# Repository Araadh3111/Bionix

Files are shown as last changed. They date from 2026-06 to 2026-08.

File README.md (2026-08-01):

# Bionix 
## video of the servo opening and closing 
https://www.youtube.com/watch?v=JQe1FLX11hM

An open-source, EMG-controlled bionic hand engineered for the IRIS National Science Fair. Bionix features a custom tendon-driven mechanical design, frictionless brass-rod joints, and an antagonistic elastic return system.

## Overview
Bionix translates raw electromyography (EMG) signals from the user's forearm into precise, articulated finger movements. The system uses a Raspberry Pi Pico to process analog muscle signals and distribute PWM control to a 5-servo array housed inside a custom 3D-printed palm cavity. 

## Features
* **Tendon-Driven Kinematics:** Uses high-tensile braided lines for active flexion and a shock-cord elastic system for passive extension, eliminating the "bowstring" effect.
* **Low-Friction Joints:** Completely screwless 3D-printed phalanges rotating on smooth 2.2mm solid brass dowel pins.
* **Myoelectric Control:** Integrated MyoWare 2.0 sensor for direct muscle-to-machine actuation.
* **Modular Power:** Safely steps down a 7.4V 2S Li-ion battery to 5V (via a 3A+ buck converter) to handle maximum servo stall torque without browning out the logic board.

## System Architecture & Diagrams

### Build progress (signals + enveloping signals)
fds

### Circuit Design and WIRING diagram


### Assembled Design 


### printed hand

### Electronics + hand



# How do I plan on reading Neural signals from the brain
its pretty simple actually, my brain wants to close my hand --> it fires a nerve signal to forearm muscle, which in turn produces a tiny electrical voltage on our skin, electrode pads on our forearm pick up that voltage, the voltage is now pretty weak for the raspberry to read it so the myoware board amplifies it and smooths it into a clean signal. the signal then goes into picos adc pin. then the pico maps out the no to servo position in turn fingers curl

## File Structure

Bionix/

├── CAD/                  # Fusion 360 models, assemblies, and STL files for 3D printing

├── circuit design/       # KiCad schematics (Peak.kicad_sch) for power and signal routing

├── Code/                 # Control software for the Raspberry Pi Pico

├── BOM.csv              # Complete Bill of Materials and cost breakdown

└── README.md             # Project documentation (You are here)

## Hardware Requirements
* Raspberry Pi Pico (RP2040/RP2350)
* 5x Servos (MG90s)
* 1x MyoWare 2.0 Muscle Sensor & Disposable Electrodes
* 1x 5V Buck Converter (>= 3A Output) & 2S Li-ion Battery
* 3D Printed Parts (PLA/PETG recommended)
* *For a full parts list, cost breakdown, and assembly hardware, please refer to the `BOM.csv` file.*

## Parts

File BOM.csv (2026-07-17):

Item | Qty | Unit Cost (USD) | Total (USD) | Source | Notes
MG90S metal-gear servo (test pair) | 2 | 2.98 | 5.96 | https://zbotic.in/product/mg90s-9g-servo-metal-gear-180-degrees-superior-quality/ | Rs.256 verified. 180-deg positional. Pull-test before buying reserve.
MG90S metal-gear servo (reserve) | 3 | 2.98 | 8.945 | https://zbotic.in/product/mg90s-9g-servo-metal-gear-180-degrees-superior-quality/ | Ordered after pull-test passes.
Robocraze EMG muscle sensor kit | 1 | 23.60 | 23.60 | https://www.amazon.in/Robocraze-Muscle-Signal-Sensor-Professional/dp/B073B8P5J9 | Rs.2029. Grip intent signal. Already on hand.
ECG/EMG electrode pads (100 pack) | 1 | 6.78 | 6.78 | https://www.amazon.in/TenTabs-Disposable-Electrodes-Adhesive-Monitoring/dp/B0FRG1DRJ1 | Rs.583. Consumable - fresh pads every EMG session.
Raspberry Pi Pico 2 | 1 | 5.80 | 5.80 | https://robu.in/product/raspberry-pi-pico-2/ | ~Rs.500 - confirm at checkout. New purchase; existing Pico H committed to Vega. RP2350 headroom for EMG processing.
UBEC 5V/7A regulator | 1 | 5.69 | 5.69 | https://www.indianhobbycenter.com/products/ubec-5v-7a | Rs.489. Servo power rail. Already on hand.
Brass rod 2mm dia (10pc) | 1 | 6.97 | 6.97 | https://www.amazon.in/Priyanshu-Decor-10Pcs-Welding-Brazing/dp/B0BZQQDHLJ | Rs.599. CAD joint holes being updated 2.4mm -> 2.05mm to match.
Braided fishing line 40lb 4-strand | 1 | 4.10 | 4.10 | https://www.amazon.in/Pro-Hunter-Fishing-Strands-Accessory/dp/B0CPVNPMRZ?mcid=712e7af3f7ac3c0ebace684aafd9efc9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 | ~Rs.350. Search 'braided fishing line 40lb' on Amazon.in - Ashconfish / Hercules / LinHiver 100m spool all fit. Flexor tendons.
Elastic cord 1.5mm | 1 | 8.13 | 8.13 | https://www.amazon.in/OMX-Elastic-Stretch-Boutique-Bracelet/dp/B09HPSD8BX | Rs.699 / 96m. Extensor return.
PTFE bowden tube 2mm ID x 4mm OD | 1 | 1.73 | 1.73 | https://novo3d.in/blue-ptfe/ | Rs.149 / 1m. Low-friction liner for palm-to-dorsal tendon turn.
TOTAL |  |  | 77.70 |  | ~Rs.6,680. Filament self-funded and excluded. ~Rs.2,520 already on hand (EMG kit + UBEC).

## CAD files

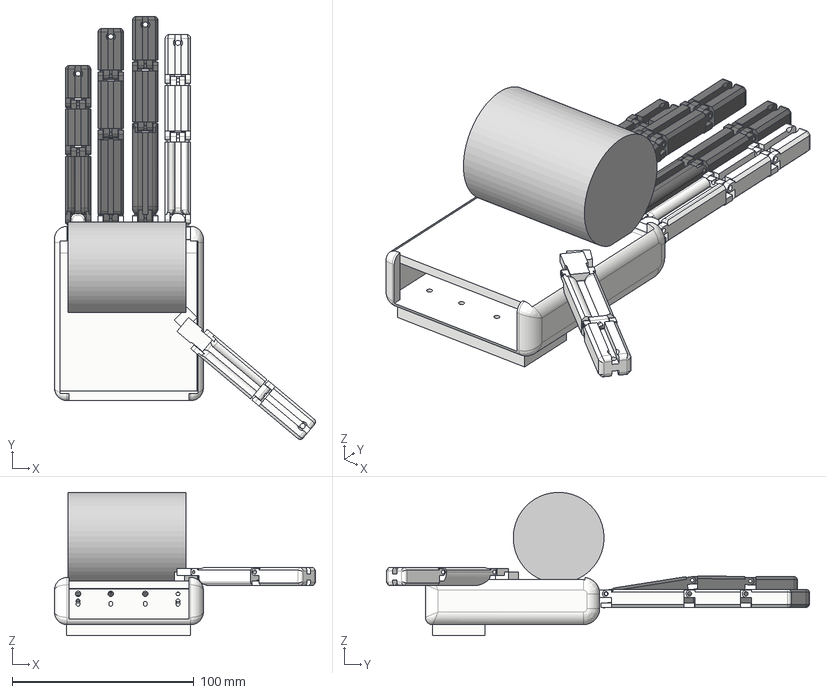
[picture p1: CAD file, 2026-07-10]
CAD/completehand.step
143.8 x 232.9 x 78.8 mm

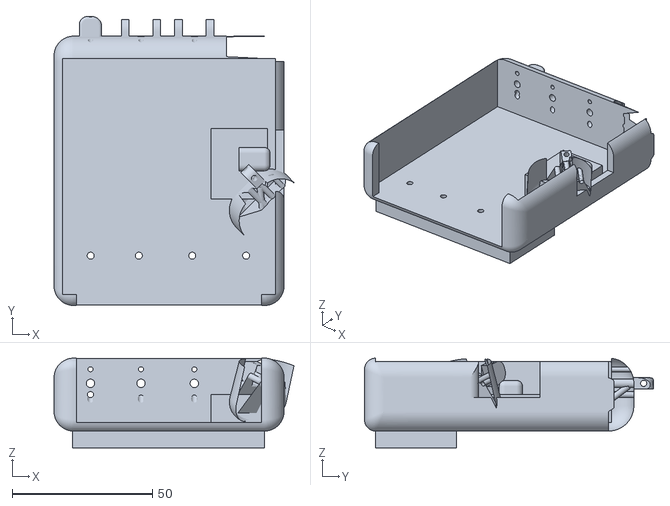
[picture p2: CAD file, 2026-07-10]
CAD/Palm/palm_complete.stl
85.5 x 103.0 x 32.0

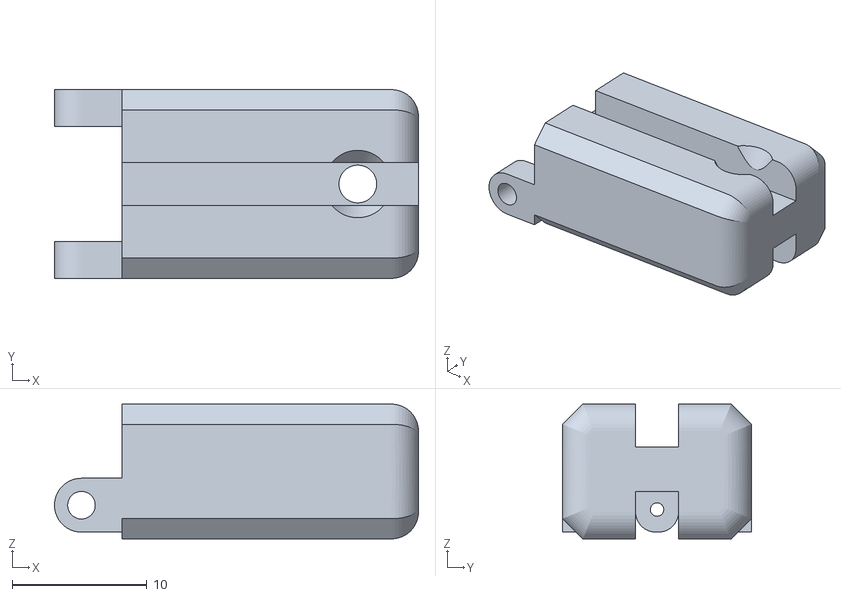
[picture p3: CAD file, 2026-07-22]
CAD/index finger/index_distal.stl
27.0 x 14.0 x 10.0

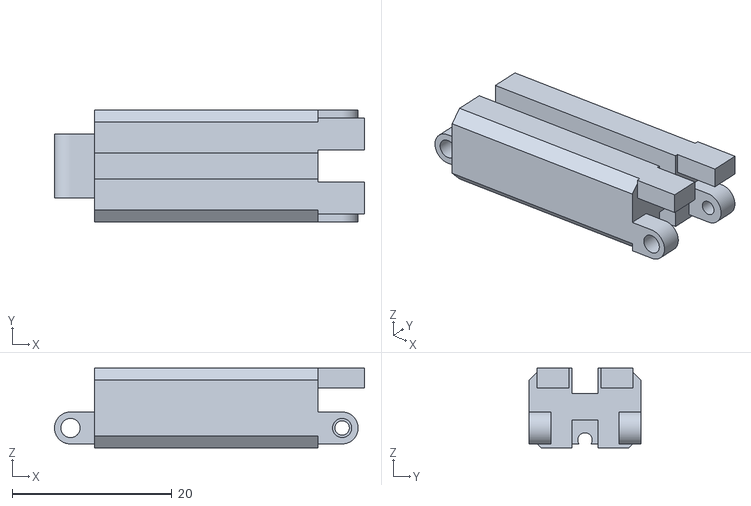
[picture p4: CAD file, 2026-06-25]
CAD/middle finger/middle_middle.stl
38.8 x 14.0 x 10.0

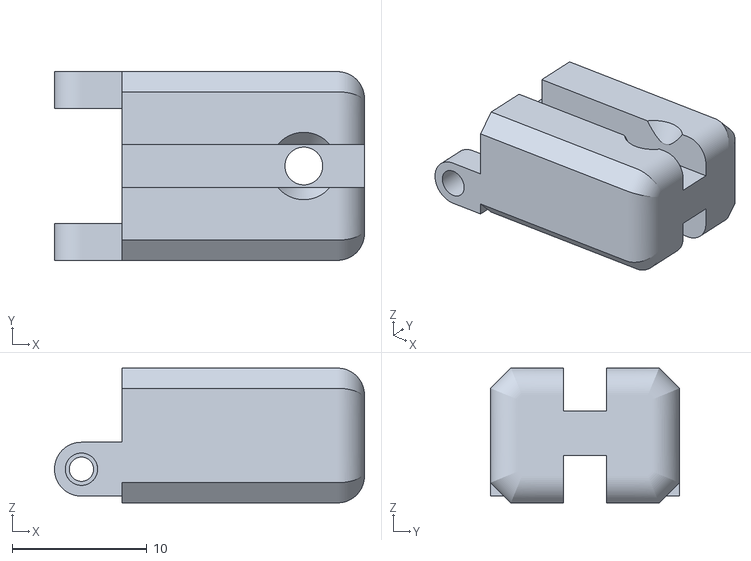
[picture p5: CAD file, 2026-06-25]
CAD/pinky finger/pinky_distal.stl
23.0 x 14.0 x 10.0

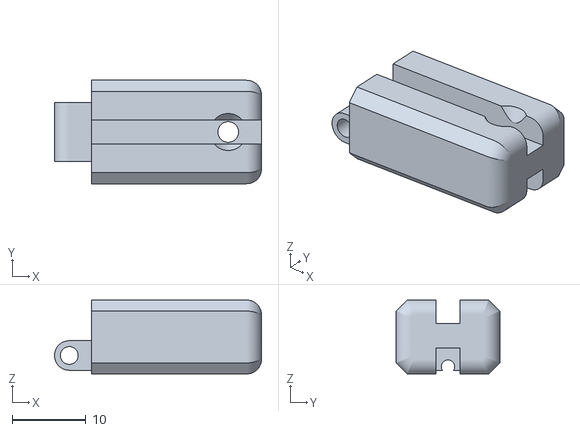
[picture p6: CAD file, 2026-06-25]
CAD/ring finger/ring_distal.stl
28.0 x 14.0 x 10.0

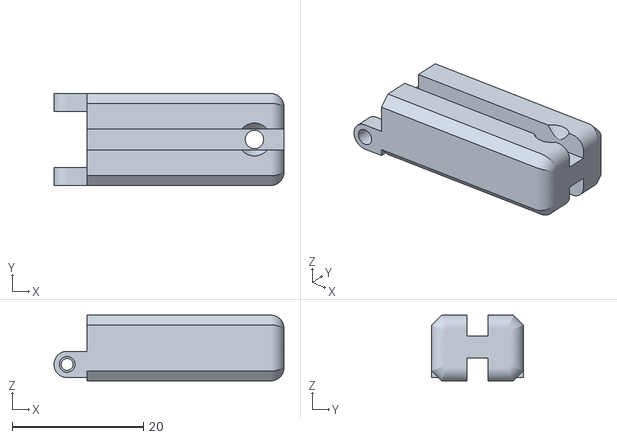
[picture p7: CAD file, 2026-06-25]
CAD/thumb/thumb_distal.stl
35.0 x 14.0 x 10.0

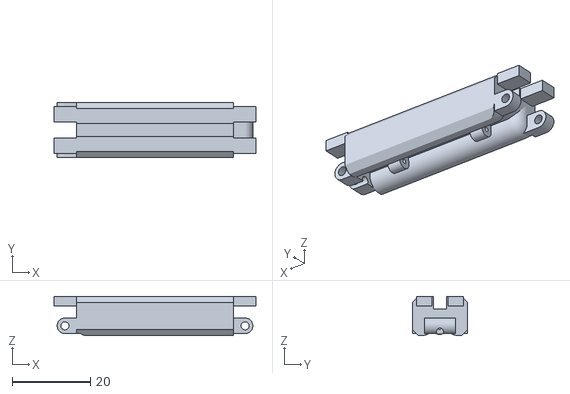
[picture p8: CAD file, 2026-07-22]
CAD/index finger/index_proximal.stl
51.6 x 14.0 x 10.0

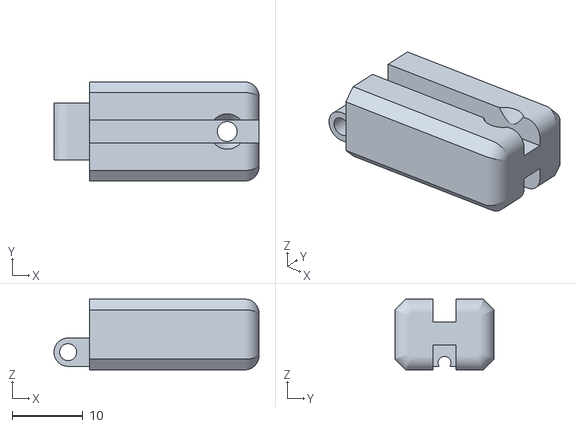
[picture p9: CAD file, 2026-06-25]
CAD/middle finger/middle_distal.stl
29.0 x 14.0 x 10.0

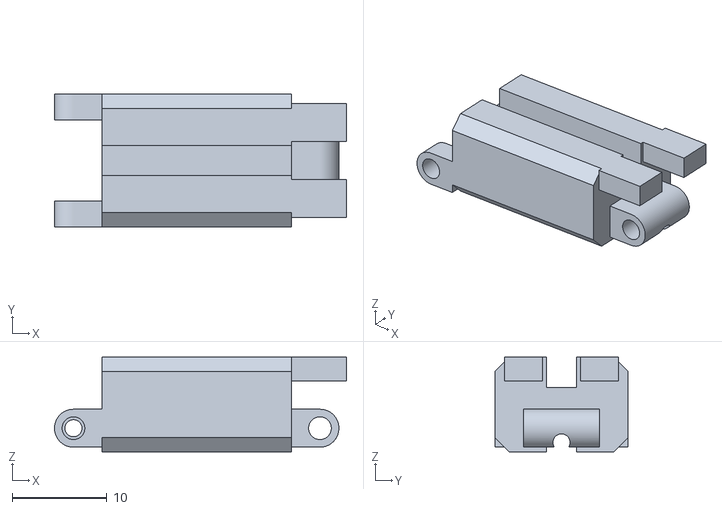
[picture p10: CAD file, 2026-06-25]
CAD/pinky finger/pinky_middle.stl
30.8 x 14.0 x 10.0

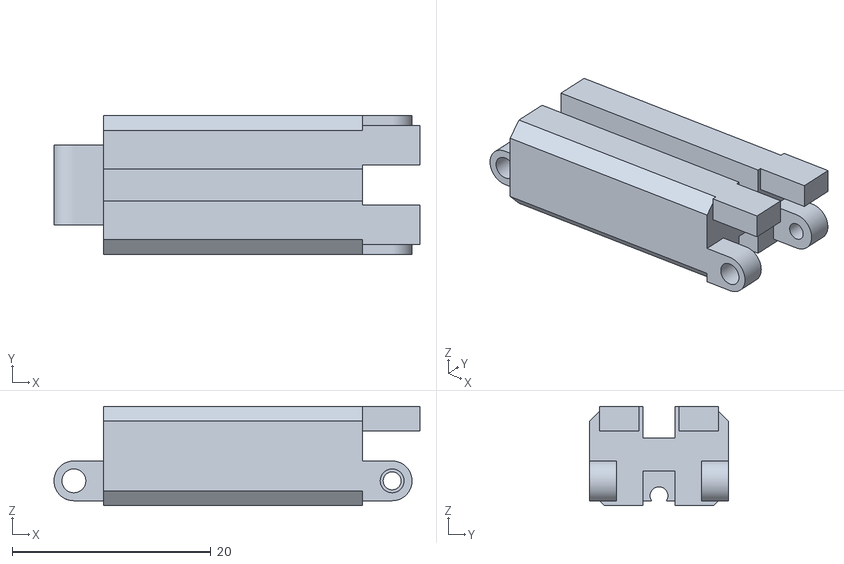
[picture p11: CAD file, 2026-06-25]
CAD/ring finger/ring_middle.stl
36.8 x 14.0 x 10.0

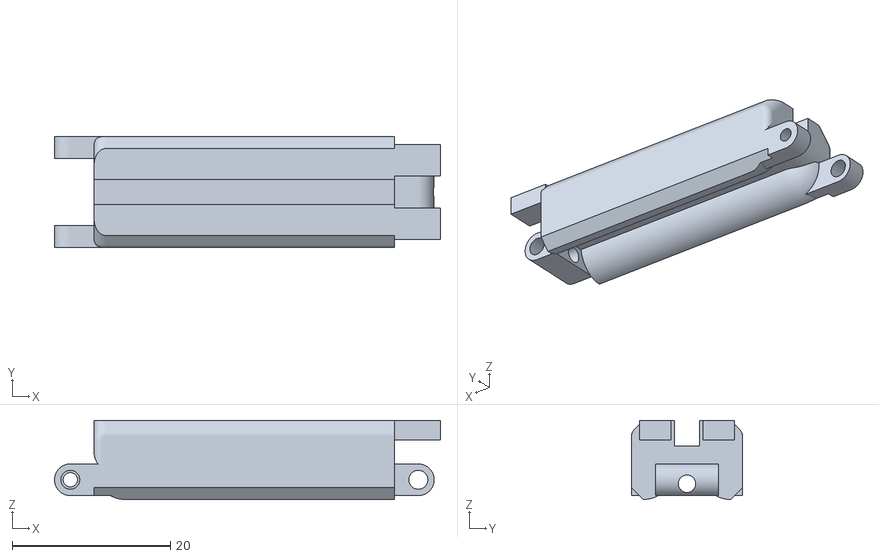
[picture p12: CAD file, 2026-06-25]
CAD/thumb/thumb_proximal.stl
48.8 x 14.0 x 10.0

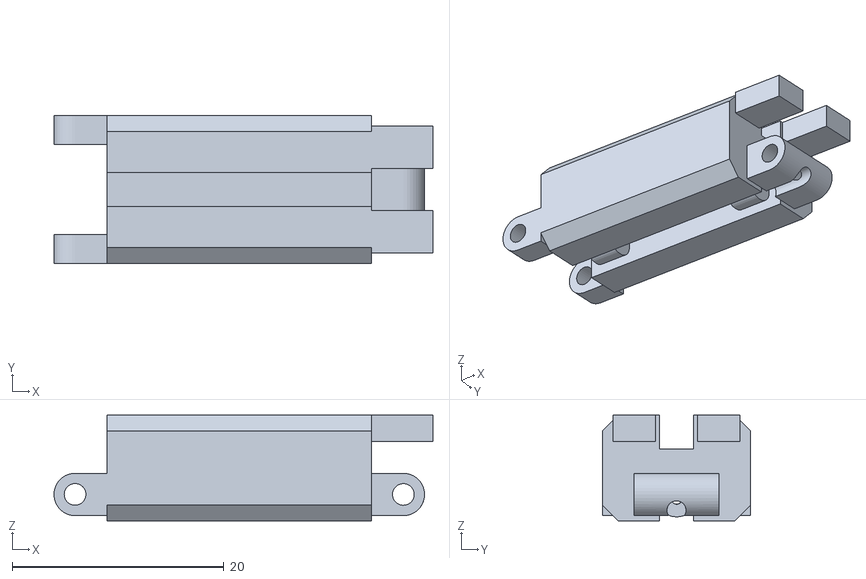
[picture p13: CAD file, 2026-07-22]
CAD/index finger/index_middle.stl
35.8 x 14.0 x 10.0

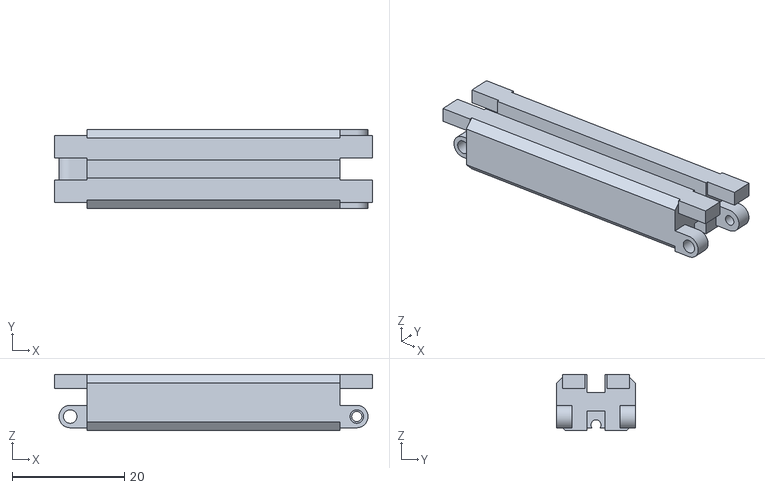
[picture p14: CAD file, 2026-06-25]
CAD/middle finger/middle_proximal.stl
56.6 x 14.0 x 10.0

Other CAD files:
CAD/pinky finger/pinky_proximal.stl
CAD/ring finger/ring_proximal.stl
CAD/completehand.stl

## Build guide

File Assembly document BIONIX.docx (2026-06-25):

# Assembly document BIONIX:-

## Parts list→ servos, RP2040, EMG sensor, wires, threads, elastics, brass rods etc ( to know more about hardware parts refer to BOM.csv)

## Finger Assembly →

A finger contains three parts, the proximal phalanx or the segment that connects to the palm, the middle segment and the distal segment. To connect these all I will be using brass rods of 2mm and insert them in the holes I have made to connect each segment to other also known as the fork and tongue method of connecting or simulating joints

## Thread routing→

A fishing line thread knotted at the very top of the distal phalange runs through the three segments to the palm to create tension, to ensure the threads don’t slip out of the groove channel I have printed small u shaped things to keep it in place from the palm the thread goes to actuator which moves it

## Elastic Routing→

An elastic band running from the top of distal segment to the rectangle box in the bottom portion of the palm to make the finger curl back after pulling

### How does the thumb differ from other fingers?

- Other fingers connect to the palm by a fork or a tongue placed at the top of the palm, the thumb is placed in a unique way by cutting a rectangle shaped cut in the palm and making a thumb mount.

# The electronics:

I am using a raspberry pi("RP2040 / Pico" ) , 5 servos, battery, buck converter and a myoware sensor as my main circuit components. The 5 servos constitute an actuation mechanism where the fishing lines end up getting pulled thus moving the finger the emg sensor picks up signals from the muscle to being contraction or relaxation of the fingers

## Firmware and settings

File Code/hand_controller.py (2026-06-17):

# =====================================================================
#  Unbound Bionics - hand controller  (Raspberry Pi Pico / MicroPython)
#  Pin map taken directly from Peak.net schematic:
#     Thumb  servo -> GPIO10   Index servo -> GPIO11
#     Middle servo -> GPIO12   Ring  servo -> GPIO13
#     Pinky  servo -> GPIO14
#     EMG signal   -> GPIO26 (ADC0)
#  Servos powered from 5V (buck), signal lines from the Pico GPIO.
# =====================================================================

from machine import Pin, PWM, ADC
import time

# ---------- servo driver ----------
SERVO_FREQ = 50          # 50 Hz standard hobby servo
MIN_US = 500             # pulse width at 0 deg   (tune per servo)
MAX_US = 2500            # pulse width at 180 deg (tune per servo)

class Servo:
    def __init__(self, gpio, open_deg=0, closed_deg=110):
        self.pwm = PWM(Pin(gpio))
        self.pwm.freq(SERVO_FREQ)
        self.open_deg = open_deg        # finger straight / open
        self.closed_deg = closed_deg    # finger curled / closed
        self.write(open_deg)

    def write(self, deg):
        deg = max(0, min(180, deg))
        us = MIN_US + (MAX_US - MIN_US) * deg / 180
        # duty_u16: fraction of the 20 ms (20000 us) period
        duty = int(us / 20000 * 65535)
        self.pwm.duty_u16(duty)
        self._deg = deg

    def open(self):   self.write(self.open_deg)
    def close(self):  self.write(self.closed_deg)
    def to(self, frac):  # frac 0.0 (open) .. 1.0 (closed)
        self.write(self.open_deg + (self.closed_deg - self.open_deg) * frac)

# ---------- map fingers to the schematic pins ----------
thumb  = Servo(10)
index  = Servo(11)
middle = Servo(12)
ring   = Servo(13)
pinky  = Servo(14)
FINGERS = [thumb, index, middle, ring, pinky]

# ---------- EMG input ----------
emg = ADC(Pin(26))       # ADC0
def read_emg():
    # average a few samples to smooth noise
    s = 0
    for _ in range(16):
        s += emg.read_u16()
    return s // 16

# ---------- grip presets ----------
def grip_open():
    for f in FINGERS: f.open()

def grip_fist():
    for f in FINGERS: f.close()

def grip_pinch():
    # thumb + index close, rest open  (pinch / hold a pen)
    thumb.close(); index.close()
    middle.open(); ring.open(); pinky.open()

def grip_point():
    # index out, rest closed
    index.open()
    thumb.close(); middle.close(); ring.close(); pinky.close()

def grip_write():
    # writing tripod: thumb + index + middle lightly closed
    thumb.to(0.7); index.to(0.7); middle.to(0.6)
    ring.close(); pinky.close()

# ---------- smooth move (so it doesn't snap) ----------
def smooth_to(frac, steps=20, dly=0.02):
    start = [f._deg for f in FINGERS]
    target = [f.open_deg + (f.closed_deg - f.open_deg) * frac for f in FINGERS]
    for s in range(steps + 1):
        for i, f in enumerate(FINGERS):
            f.write(start[i] + (target[i] - start[i]) * s / steps)
        time.sleep(dly)

# =====================================================================
#  MODE 1 - EMG control
#  Flex muscle -> hand closes. Relax -> opens.
# =====================================================================
EMG_BASELINE = 8000      # calibrate: resting EMG value
EMG_THRESHOLD = 18000    # calibrate: flex above this = close

def calibrate_emg():
    print("Relax your arm... measuring baseline")
    time.sleep(2)
    vals = [read_emg() for _ in range(50)]
    base = sum(vals) // len(vals)
    print("baseline =", base)
    return base

def run_emg_mode():
    base = calibrate_emg()
    thresh = base + 10000
    print("EMG mode running. Flex to close.")
    while True:
        v = read_emg()
        # map EMG strength to grip fraction
        if v > thresh:
            frac = min(1.0, (v - base) / (thresh - base) - 0.0)
            for f in FINGERS: f.to(min(1.0, frac))
        else:
            grip_open()
        time.sleep(0.05)

# =====================================================================
#  MODE 2 - preset cycle (good for the 90-second demo / no EMG)
#  Cycles open -> fist -> pinch -> write so you can film it.
# =====================================================================
def run_demo_cycle():
    seq = [("open", grip_open), ("fist", grip_fist),
           ("pinch", grip_pinch), ("write", grip_write)]
    while True:
        for name, fn in seq:
            print("grip:", name)
            fn()
            time.sleep(2)

# =====================================================================
#  pick a mode here
# =====================================================================
if __name__ == "__main__":
    grip_open()
    time.sleep(1)
    # run_emg_mode()      # <- uncomment for EMG control
    run_demo_cycle()      # <- preset demo cycle (default)

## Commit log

2026-06-17 initial designs have to fix thumb problem
    [BOM.csv, index_distal.step, index_middle.step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]
2026-06-18 Complete assembled hand + New palm design with thumb mount
    [Peak.kicad_sch, completehand.step, palm_complete.step]
2026-06-18 changed BOM
    [BOM.csv]
2026-06-18 changed servo in bom
    [BOM.csv]
2026-06-18 Update servo item in BOM.csv
    [BOM.csv]
2026-06-18 Change BOM file format from XLSX to CSV
2026-06-22 updated bom
    [BOM.csv]
2026-06-25 changed files to stl and added assembly doc as requested
    [completehand.step, index_distal.step, index_distal.stl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]
2026-06-28 Update README with new image and hardware details
    Added image of printed hand and updated servo model in hardware requirements.
2026-07-10 added compelete hand files
    [completehand.step, completehand.stl, palm_complete.stl]
2026-07-10 moved the files in CAD folder
    [completehand.step, completehand.stl]
2026-07-11 Update servo model from MG996r to MG90s
2026-07-12 Revise BOM with updated item costs and sources
    Updated item details and costs in BOM, including new sources and notes.
    [BOM.csv]
2026-07-12 Revise BOM with updated components and pricing
    Updated BOM with new items, quantities, and costs.
    [BOM.csv]
2026-07-17 Fix total cost for MG90S metal-gear servo (reserve)
    Corrected total cost for reserve MG90S servo.
    [BOM.csv]
2026-07-22 added thread routing arches!
    [index_distal.stl, index_middle.stl, index_proximal.stl]
2026-07-29 Update README with build progress and circuit diagram
    Added build progress image and updated circuit design diagram.
